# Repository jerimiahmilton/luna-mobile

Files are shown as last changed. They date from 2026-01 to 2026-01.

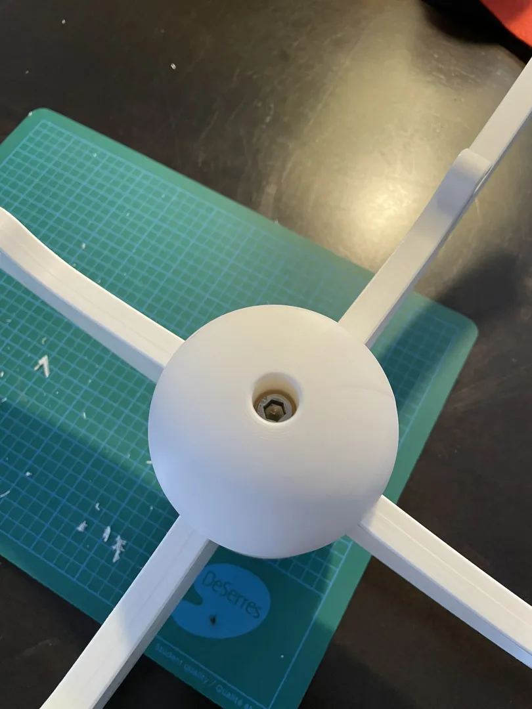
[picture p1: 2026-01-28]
reference/3mf_contents/Auxiliaries/Model Pictures/IMG_5841.webp

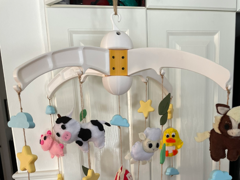
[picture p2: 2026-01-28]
reference/3mf_contents/Auxiliaries/.thumbnails/thumbnail_3mf.png

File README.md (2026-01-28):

# 🌙 Luna's Baby Mobile

A beautiful, motorized baby mobile designed for 3D printing. This project creates a gently rotating mobile that can be mounted to a ceiling or crib rail.

## ✨ Features

- **Motorized rotation** - Gentle ~3.75 RPM rotation using an N20 worm gear motor
- **Simple design** - Single-stage gear reduction (8:1) for reliability
- **Two mounting options** - Ceiling mount or adjustable crib rail clamp
- **Modular design** - 4 interchangeable arms with various hook styles
- **Dual power options** - 4xAA battery pack OR DC barrel jack for wall power
- **Baby-safe** - Rounded edges, no pinch points, secure mounting
- **Fully parametric** - Easy to customize dimensions in OpenSCAD
- **Easy assembly** - Press-fit and snap-fit connections

## 📦 What's Included

### OpenSCAD Files
| File | Description |
|---|---|
| `config.scad` | All parameters and dimensions |
| `gears.scad` | Involute gear generation library |
| `motor_mount.scad` | N20 motor housing (single shaft version) |
| `gear_assembly.scad` | Single-stage gear reduction (8:1) |
| `central_hub.scad` | Main hub with bearing seat |
| `arm_curved.scad` | **Curved arms with integrated hooks** (default) |
| `arm_straight.scad` | Original straight arms with end hooks |
| `ceiling_mount.scad` | Ceiling mounting bracket |
| `crib_clamp.scad` | Adjustable crib rail clamp |
| `battery_mount.scad` | 4xAA battery case holder |
| `switch_mount.scad` | Power switch bracket |
| `barrel_jack.scad` | DC barrel jack mount |
| `pdb_mount.scad` | Power Distribution Board (IA005) mount |
| `assembly.scad` | Complete assembly visualization |

### Pre-rendered STL Files
Located in `openscad/stl/` for immediate printing.

## 🔧 Specifications

### Motor (N20 Worm Gear - B-LA008, Single Shaft)
| Parameter | Value |
|---|---|
| Voltage | 6V DC (range: 3-7V) |
| Speed | ~30 RPM @ 6V |
| Shaft | Single, 4mm with D-flat |
| Current | ≤30mA |
| Direction | Clockwise |

### Bearing (608)
| Parameter | Value |
|---|---|
| Inner diameter | 8mm |
| Outer diameter | 22mm |
| Width | 7mm |

### Gear Reduction (Simplified!)
| Stage | Pinion | Gear | Ratio | Input RPM | Output RPM |
|---|---|---|---|---|---|
| Single | 12T | 96T | 8:1 | ~30 | **~3.75** |

*Much simpler than the previous two-stage 50:1 design!*

### Power Options

**Option 1: Battery Power (4xAA)**
| Parameter | Value |
|---|---|
| Voltage | 6V (4 × 1.5V) |
| Battery Case | IA003 (70×65×19mm) |
| Connector | PH2.0 |
| Runtime | ~40-60 hours |

**Option 2: Wall Power (DC Adapter)**
| Parameter | Value |
|---|---|
| Voltage | 6V DC |
| Jack | 5.5×2.1mm barrel |
| Current | 500mA+ recommended |

## 🛒 Bill of Materials

See [BOM.md](BOM.md) for the complete parts list with links and prices.

### Quick Parts List
- 1× N20 Worm Gear Motor (6V, ~30RPM, B-LA008)
- 2× 608 Bearings
- 1× 4xAA Battery Case (IA003, PH2.0)
- 1× Power Switch (XA007, XH2.54)
- 1× DC Barrel Jack (optional, XC008)
- Fasteners (M3, M4 screws)
- Wire, connectors

## 🖨️ Printing Guidelines

### Recommended Settings
| Setting | Value |
|---|---|
| Layer height | 0.2mm |
| Infill | 20-30% |
| Material | PLA or PETG |
| Supports | Only where noted |

### Print Times (approximate)
| Part | Time | Supports |
|---|---|---|
| Central Hub | 2-3 hours | No |
| Arms (×4) | 1 hour each | No |
| Ceiling Mount | 2 hours | Yes |
| Crib Clamp | 3-4 hours | Yes |
| Motor Mount | 1 hour | Minimal |
| Gear Housing | 1.5 hours | No |
| Motor Pinion | 15 min | No |
| Output Gear | 1 hour | No |
| Battery Mount | 1.5 hours | No |
| Switch Mount | 30 min | No |
| Barrel Jack Mount | 30 min | No |

### Tolerances
Adjust in `config.scad` if needed:
- Press fit: 0.15mm
- Loose fit: 0.3mm
- General: 0.2mm

## 🔨 Assembly Instructions

### 1. Print All Parts
Use the settings above. Check each part for quality before assembly.

### 2. Install Bearings
Press 608 bearings into:
- Ceiling mount (or crib clamp) bearing seat
- Gear housing output shaft position

### 3. Assemble Gear Train (Simplified!)
1. Press motor pinion (12T) onto motor D-shaft
2. Mount output gear (96T) on output shaft with bearing
3. Install gear housing with motor pinion engaged
4. Close gearbox with lid

### 4. Attach Motor to Mount
1. Slide motor into motor mount housing
2. Clips will snap over motor body
3. Route wires through exit slot

### 5. Assemble Hub & Arms
1. Insert arms into hub sockets (they snap-fit)
2. Attach hub adapter through bearing to output gear
3. Verify smooth rotation

### 6. Mount Assembly

**Ceiling Mount:**
1. Mark ceiling holes using mount as template
2. Install wall anchors if needed
3. Secure mount with M4 screws
4. Attach motor/gearbox assembly
5. Hang hub assembly

**Crib Clamp:**
1. Position clamp on crib rail
2. Tighten adjustment knob
3. Verify secure grip (no movement)
4. Attach mobile assembly

### 7. Electronics Assembly

**Wiring with Power Distribution Board (IA005):**

The IA005 provides clean power management with overcurrent protection and multiple outputs.

```
┌─────────────────────────────────────────────────────────────────────────┐
│                    POWER DISTRIBUTION WIRING                            │
├─────────────────────────────────────────────────────────────────────────┤
│                                                                         │
│  ┌─────────────┐      ┌─────────────────────────────────┐              │
│  │ 4xAA Battery│─────→│ IN (PH2.0)                      │              │
│  │   (IA003)   │      │                                 │              │
│  │   (PH2.0)   │      │         IA005 PDB               │              │
│  └─────────────┘      │   Power Distribution Board      │              │
│                       │                                 │              │
│  ┌─────────────┐      │ SW0 (SH1.0) ←── Master Switch   │              │
│  │ XA007 Switch│─────→│ (controls all outputs)          │              │
│  │  (XH2.54*)  │      │                                 │              │
│  └─────────────┘      │ CH1 (SH1.0) ───→ Motor ─────────┼──→ 🔄        │
│                       │ CH2 (SH1.0) ───→ (spare)        │              │
│  * May need adapter   │ CH3 (SH1.0) ───→ (spare)        │              │
│    or rewire to SH1.0 │ CH4 (SH1.0) ───→ (spare)        │              │
│                       │                                 │              │
│                       │ 💡 LED: White = OK              │              │
│                       │        Off = Overcurrent        │              │
│                       └─────────────────────────────────┘              │
│                                                                         │
└─────────────────────────────────────────────────────────────────────────┘
```

**Connection Summary:**
| From | To | Cable Type |
|---|----|---|
| Battery Case (IA003) | IA005 IN | PH2.0-2P (included) |
| IA005 CH1 | Motor | SH1.0-2P (included) |
| XA007 Switch | IA005 SW0 | SH1.0-2P* |

*Note: XA007 switch uses XH2.54 connector. You may need to re-terminate with SH1.0 or use an adapter.

**LED Indicator Behavior:**
- ⚪ **White LED ON** = Normal operation, power flowing
- ⚫ **LED OFF** = Overcurrent protection triggered (>1A), check connections

**Benefits of IA005:**
- ✅ Clean power distribution with labeled ports
- ✅ Overcurrent protection (max 1A per channel)
- ✅ Master switch input (SW0) controls all outputs
- ✅ 4 spare outputs for future accessories (LEDs, sensors, etc.)
- ✅ Easy daisy-chaining via OUT port

**Alternative: Direct Wiring (without PDB)**
```
┌─────────────┐    ┌──────────┐    ┌─────────┐
│ 4xAA Battery│───→│  Switch  │───→│  Motor  │
│   (PH2.0)   │    │ (XH2.54) │    │         │
└─────────────┘    └──────────┘    └─────────┘
```

**Alternative: Wall Power**
```
┌────────────┐    ┌──────────┐    ┌─────────┐
│ DC Adapter │───→│  Switch  │───→│  Motor  │
│ (6V, 5521) │    │ (XH2.54) │    │         │
└────────────┘    └──────────┘    └─────────┘
```

### 8. Add Mobile Elements
Hang decorative elements from arm hooks using string or fishing line.

## ⚠️ Safety Notes

- **Always supervise** - Never leave baby unattended with mobile
- **Height** - Mount at least 16" above mattress (out of reach)
- **Secure mounting** - Test stability before use
- **Regular inspection** - Check for loose parts weekly
- **Age limit** - Remove mobile when baby can push up on hands/knees (~5 months)
- **Cord safety** - Keep power cords away from crib, use cord covers

## 🎨 Customization

### Changing Dimensions
Edit `config.scad` to adjust:
- `arm_length` - Length of arms (default 180mm)
- `hub_arm_count` - Number of arms (default 4)
- `gear_module` - Gear size (affects overall gearbox size)
- `motor_rpm` - If using a different speed motor

### Arm Styles

Luna Mobile includes two arm designs:

**🌊 Curved Arms (Default)** — `arm_curved.scad`
- Elegant sweeping arc shape inspired by Scandinavian design
- **Two integrated downward-facing hooks** per arm for hanging decorations
- Decorative recessed channel along the top surface
- Mounting holes for secure hub attachment
- Perfect for the main decorative elements

**➖ Straight Arms** — `arm_straight.scad`
- Simple, clean design with hook at the end
- Multiple hook styles available:
  - Default curved hook
  - Loop hook
  - Star hook
  - Moon hook (🌙 for Luna!)
- Good for minimalist aesthetic or more elements

To switch arm styles, edit `config.scad`:
```openscad
use_curved_arms = true;   // Curved arms with integrated hooks (default)
use_curved_arms = false;  // Original straight arms
```

### Colors
Adjust the color variables in `config.scad` for different preview colors.

## 🔌 Connector Reference

| Component | Connector | Pin Count |
|---|---|---|
| Battery Case | JST PH2.0 | 2-pin |
| Power Switch | XH2.54 | 2-pin |
| DC Barrel Jack | 5.5×2.1mm | 2-wire |
| PDB Power IN/OUT | JST PH2.0 | 2-pin |
| PDB Switch Inputs | JST SH1.0 | 2-pin |
| PDB Device Outputs | JST SH1.0 | 2-pin |

**Adapter cables** may be needed to connect these. Search for "PH2.0 to XH2.54" adapters, or make your own with crimp terminals.

**Note:** The IA005 PDB includes SH1.0 jumper cables, making it easy to connect to motors and switches directly.

## 📝 License

MIT License - See [LICENSE](LICENSE)

Feel free to modify, share, and sell prints!

## 💕 Credits

Designed with love for Luna.

Made for Jeremy's newborn daughter — may she have sweet dreams and endless wonder! 🌙✨

---

*Made with OpenSCAD and lots of coffee ☕*

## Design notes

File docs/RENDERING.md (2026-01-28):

# Rendering STL Files

The OpenSCAD files need to be rendered to STL for 3D printing.

## Using OpenSCAD GUI

1. Open any `.scad` file in OpenSCAD
2. Press F6 to render
3. Export → Export as STL

## Command Line Rendering

```bash
# Render individual parts
openscad -o stl/central_hub.stl openscad/central_hub.scad
openscad -o stl/arm.stl openscad/arm.scad
openscad -o stl/ceiling_mount.stl openscad/ceiling_mount.scad
openscad -o stl/motor_mount.stl openscad/motor_mount.scad
openscad -o stl/crib_clamp.stl openscad/crib_clamp.scad

# Render gears (export each part separately by uncommenting in gear_assembly.scad)
openscad -o stl/stage1_pinion.stl -D 'part="pinion1"' openscad/gear_assembly.scad
```

## Recommended Render Settings

For final STL export, increase resolution in `config.scad`:

```openscad
$fn = 128;  // Higher = smoother curves, longer render time
```

## Preview vs Render

- **F5 (Preview)** - Fast, for checking design
- **F6 (Render)** - Full quality, required before STL export

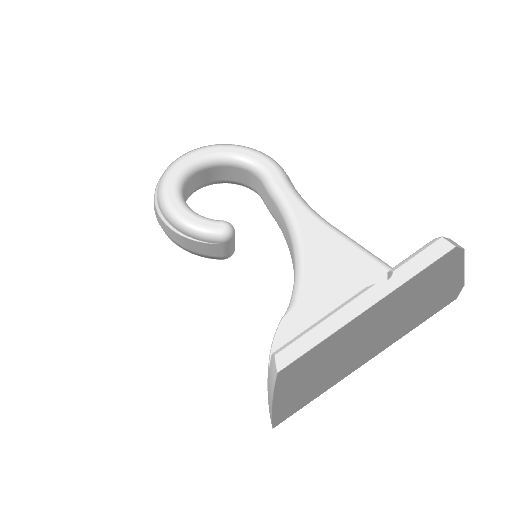
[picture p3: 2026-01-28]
reference/3mf_contents/Metadata/plate_4.png

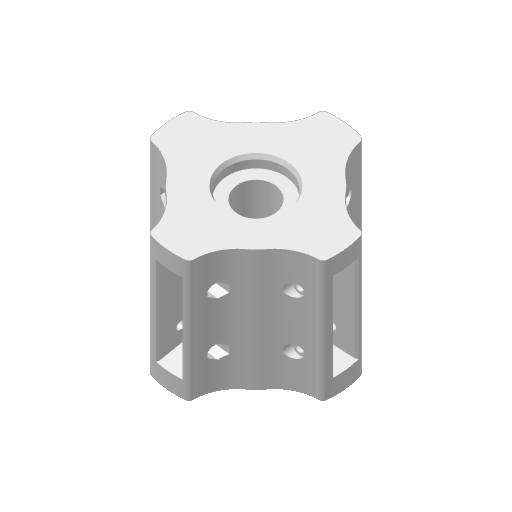
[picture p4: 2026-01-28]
reference/3mf_contents/Metadata/plate_2.png

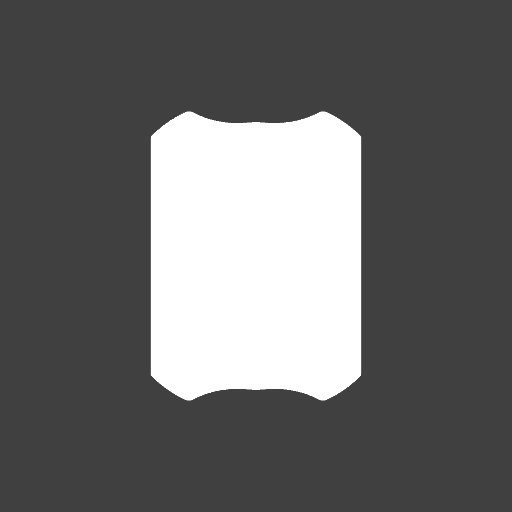
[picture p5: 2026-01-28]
reference/3mf_contents/Metadata/plate_no_light_2.png

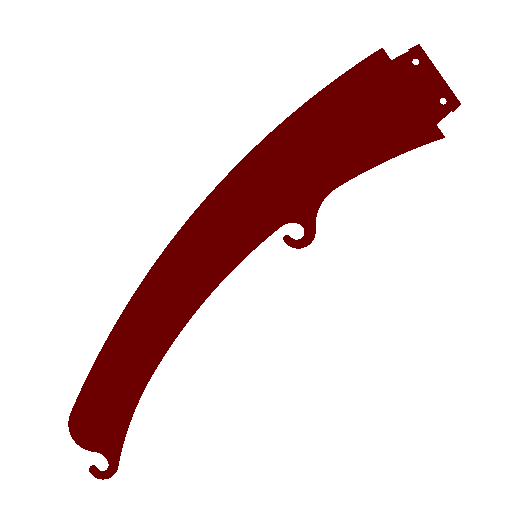
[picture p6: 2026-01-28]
reference/3mf_contents/Metadata/pick_1.png

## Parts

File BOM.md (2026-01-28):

# 📋 Bill of Materials - Luna's Baby Mobile

## 🖨️ 3D Printed Parts

### Mechanical Components
| Qty | Part | File | Print Time | Supports |
|-----|---|---|---|---|
| 1 | Central Hub | `central_hub.scad` | ~2.5 hrs | No |
| 4 | Arms | `arm.scad` | ~1 hr each | No |
| 1 | Ceiling Mount | `ceiling_mount.scad` | ~2 hrs | Yes |
| 1 | Crib Clamp Body | `crib_clamp.scad` | ~3 hrs | Yes* |
| 1 | Crib Clamp Jaw | `crib_clamp.scad` | ~1 hr | Yes* |
| 1 | Clamp Knob | `crib_clamp.scad` | ~30 min | No* |
| 1 | Motor Mount | `motor_mount.scad` | ~1 hr | Minimal |
| 1 | Gearbox Housing | `gear_assembly.scad` | ~1.5 hrs | No |
| 1 | Gearbox Lid | `gear_assembly.scad` | ~20 min | No |
| 1 | Motor Pinion (12T) | `gear_assembly.scad` | ~15 min | No |
| 1 | Output Gear (96T) | `gear_assembly.scad` | ~1 hr | No |
| 1 | Output Shaft | `gear_assembly.scad` | ~15 min | No |

*Only needed if using crib mount*

### Electronics Mounts
| Qty | Part | File | Print Time | Supports |
|-----|---|---|---|---|
| 1 | Battery Cradle Mount | `battery_mount.scad` | ~1.5 hrs | No |
| 1 | Switch Panel Mount | `switch_mount.scad` | ~30 min | No |
| 1 | Barrel Jack Mount | `barrel_jack.scad` | ~30 min | No* |
| 1 | PDB Mount (IA005) | `pdb_mount.scad` | ~45 min | No |

*Optional - only needed for wall power*

**Total print time:** ~15-18 hours (depending on mount choice and settings)

**Filament estimate:** ~250-300g PLA/PETG

---

## ⚡ Electronics

### Motor
| Qty | Item | Model | Specifications | Est. Price |
|-----|---|---|---|---|
| 1 | N20 Worm Gear Motor | B-LA008 | 6V, ~30RPM, single shaft, CW | $4-8 |

**Search terms:** "N20 worm gear motor 6V 25RPM single shaft" or "B-LA008"

**Key specs to verify:**
- Voltage: 6V (range 3-7V OK)
- Speed: 25-34 RPM
- Single shaft output (not dual)
- 4mm D-shaft

### Power Supply Components
| Qty | Item | Model | Specifications | Est. Price |
|-----|---|---|---|---|
| 1 | 4xAA Battery Case | IA003 | 70×65×19mm, PH2.0 connector | $2-4 |
| 1 | Power Switch Module | XA007 | On/Off, XH2.54 connector, 3A max | $2-3 |
| 1 | Power Distribution Board | IA005 | 53×10×10mm, 1A max, M2 mount | $5.29 |
| 1 | DC Barrel Jack* | XC008 | 5.5×2.1mm, panel mount, 12mm hole | $1-2 |
| 1 | 6V DC Adapter* | - | 5.5×2.1mm plug, 500mA+ | $5-10 |

*Optional - for wall power*

**IA005 Power Distribution Board Includes:**
- USB power cable
- PH2.0-2P wire pair (for battery connection)
- 5× SH1.0 jumper cables (for switches and device outputs)

**IA005 Specifications:**
- Size: 53 × 10 × 10mm, Weight: 3g
- Max current: 1A per channel, Max voltage: 7.4V
- Connectors: IN/OUT (PH2.0-2P), SW0-4 (SH1.0-2P), CH1-4 (SH1.0-2P)
- SW0 acts as master switch controlling all outputs
- White LED indicator (off = overcurrent protection triggered)

### Wiring & Connectors
| Qty | Item | Specifications | Est. Price |
|-----|---|---|---|
| 1 | PH2.0 to XH2.54 Adapter | 2-pin, 100-150mm | $1-2 |
| 2ft | 22-24 AWG Wire | Stranded, red & black | $2-3 |
| - | Heat Shrink Tubing | Assorted sizes | $3-5 |
| 2 | JST XH2.54 Connectors | 2-pin, male | $1-2 |

**Note:** The battery case (PH2.0) and switch (XH2.54) use different connectors. You'll need an adapter cable or make your own connections.

---

## 🔩 Bearings

| Qty | Item | Specifications | Est. Price |
|-----|---|---|---|
| 2 | 608 Bearing | 8×22×7mm, standard | $5-8 (pack of 10) |

*Standard skateboard bearings - very common and cheap!*

---

## 🔧 Hardware

### Fasteners
| Qty | Item | Use | Est. Price |
|-----|---|-----|---|
| 4 | M3 × 10mm Screw | Motor mount, electronics | $2-3 |
| 4 | M4 × 20mm Screw | Ceiling mount | $2-3 |
| 4 | M4 Wall Anchors | Ceiling (drywall) | $3-5 |
| 1 | M6 × 60mm Bolt | Crib clamp adjustment* | $1-2 |
| 1 | M6 Nut | Crib clamp* | $0.50 |
| 1 | M6 Wing Nut | Easier adjustment* | $1 |
| 4 | M2.5 × 8mm Screw | Gearbox lid | $1-2 |

*Only for crib mount option*

---

## 🎨 Decorative Elements (Optional)

### Mobile Hanging Elements
| Qty | Item | Suggestions | Est. Price |
|-----|---|---|---|
| 4-8 | Felt Shapes | Stars ⭐, moons 🌙, clouds ☁️, hearts ❤️ | $5-15 |
| 4-8 | Wooden Beads | 20-30mm, natural or painted | $5-10 |
| - | Pom Poms | Various sizes and colors | $3-5 |
| 1 | Fishing Line | 10-20lb test, clear | $3-5 |
| 1 | Embroidery Thread | For hanging elements | $2-3 |

### Finishing (Optional)
| Qty | Item | Use | Est. Price |
|-----|---|-----|---|
| 1 | Sandpaper | 220-400 grit | $3-5 |
| 1 | Primer | For painting | $5-8 |
| 1 | Acrylic Paint | Baby-safe, water-based | $3-5 |
| 1 | Clear Coat | Protective finish | $5-8 |

---

## 🛡️ Safety Items

| Qty | Item | Purpose | Est. Price |
|-----|---|---|---|
| 4 | Rubber Pads | Crib clamp grip | $3-5 |
| 1 | Cord Cover | Hide power cable | $5-10 |
| 1 | Cord Shortener | Keep cord safe | $3-5 |

---

## 💰 Cost Summary

| Category | Basic | With Decorations |
|---|---|---|
| Filament (~300g) | $6-10 | $6-10 |
| Motor | $4-8 | $4-8 |
| Bearings | $5-8 | $5-8 |
| Battery Case | $2-4 | $2-4 |
| Switch | $2-3 | $2-3 |
| Power Distribution Board (IA005) | $5-6 | $5-6 |
| Barrel Jack + Adapter | $6-12 | $6-12 |
| Connectors/Wire | $5-10 | $5-10 |
| Fasteners | $8-12 | $8-12 |
| Decorative | - | $15-35 |
| Safety Items | $10-20 | $10-20 |
| **Total** | **$55-90** | **$70-125** |

---

## 🔗 Suggested Suppliers

### Electronics & Motors
| Supplier | Notes |
|---|---|
| AliExpress | Best prices, 2-4 week shipping |
| Amazon | Fast shipping, higher prices |
| Banggood | Good selection, moderate shipping |
| Adafruit/SparkFun | Quality, US-based, premium prices |

### Hardware
| Supplier | Notes |
|---|---|
| Home Depot / Lowes | Local, immediate |
| McMaster-Carr | Professional quality |
| Amazon | Convenience, variety packs |
| Bolt Depot | Specialty fasteners |

### 3D Printing Supplies
| Supplier | Notes |
|---|---|
| Prusa | Quality filament |
| Overture | Good value on Amazon |
| Hatchbox | Popular, reliable |
| eSUN | Budget-friendly |

### Craft Supplies
| Supplier | Notes |
|---|---|
| Michaels / Joann | Local craft stores |
| Etsy | Handmade mobile elements |
| Amazon | Bulk supplies |

---

## 📝 Notes

### Motor Selection
The B-LA008 is the recommended motor. Key differences from the old design:
- **Old (B-LA009):** Dual shaft, 150 RPM @ 3V
- **New (B-LA008):** Single shaft, ~30 RPM @ 6V

The slower motor with single shaft simplifies the design significantly!

### Power Considerations
| Power Source | Voltage | Runtime | Notes |
|---|---|---|---|
| 4× AA Alkaline | 6V | 40-60 hrs | Portable, no wires |
| 4× AA Rechargeable | 4.8V | 30-50 hrs | Slightly slower rotation |
| 6V DC Adapter | 6V | Unlimited | Requires outlet nearby |

### Connector Compatibility
```
Battery Case (IA003) → PH2.0 connector
Switch (XA007)      → XH2.54 connector
```

These are different connector families! Solutions:
1. **Buy an adapter cable** - Search "JST PH2.0 to XH2.54"
2. **Make your own** - Cut and solder/crimp
3. **Bypass connectors** - Solder wires directly

### Battery Life Calculation
```
Motor current: ~30mA
AA battery capacity: ~2000mAh (alkaline)
Runtime: 2000 ÷ 30 = ~66 hours theoretical
Real-world: ~40-60 hours (accounting for losses)
```

---

## 🌙 For Luna

This mobile was designed with love for Jeremy's newborn daughter Luna. May the gentle rotation and soft decorations bring her peaceful dreams!

💕 Made with care, powered by coffee ☕

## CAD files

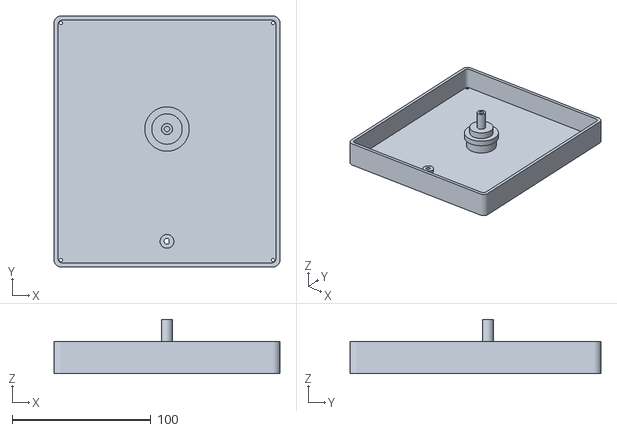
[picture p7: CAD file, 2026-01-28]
stl/gear_assembly.stl
163.0 x 181.0 x 39.0

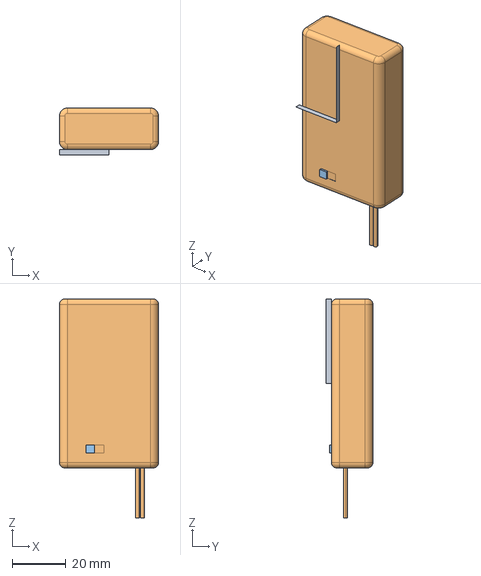
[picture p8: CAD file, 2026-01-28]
models/Battery Case/3x1.5V AAA Battery Case with XH2.54 Connector-XA012/3x1.5V AAA Battery Case with XH2.54 Connector-XA012.stp
37.0 x 17.5 x 81.7 mm

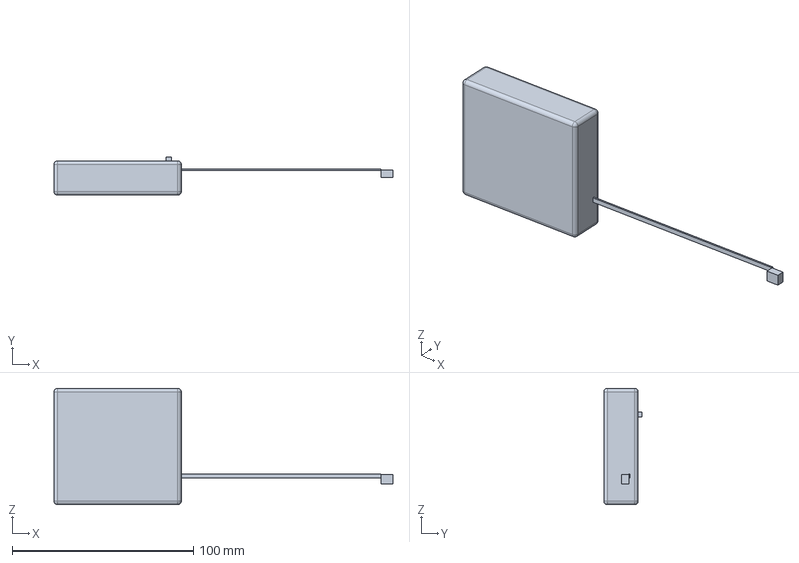
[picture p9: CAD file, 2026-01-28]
models/Battery Case/Battery Case with PH2.0 Connector - IA003/AA_battery_case_with_wire_ph2_0.stp
186.9 x 21.2 x 64.2 mm

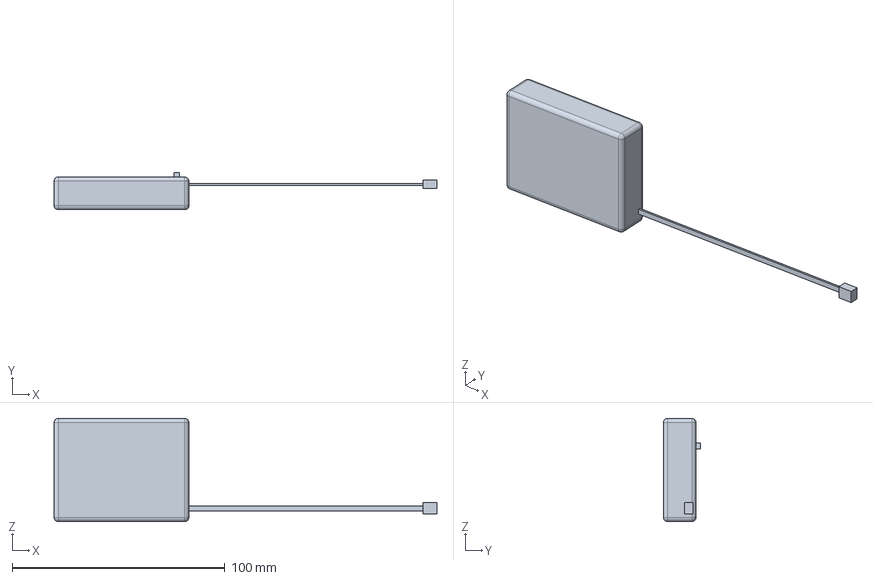
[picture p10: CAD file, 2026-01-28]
models/Battery Case/Battery Case with PH2.0 Connector - IA004/AAA_battery_case_with_wire_ph2_0.stp
180.2 x 17.6 x 48.5 mm

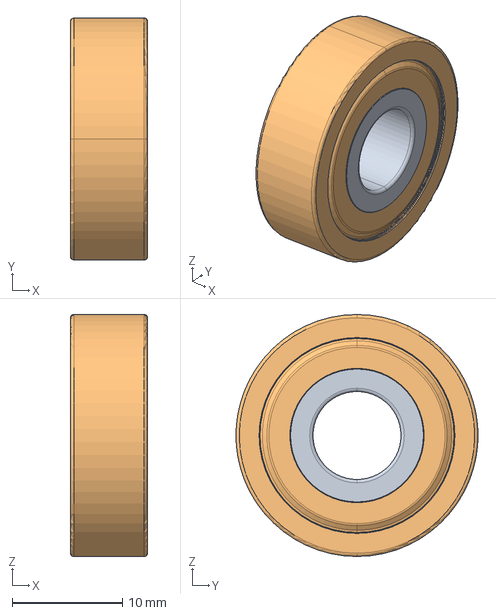
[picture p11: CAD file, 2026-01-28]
models/High Performance Bearings/608 Open - EA029/608 Open - EA029.stp
7.00 x 22.0 x 22.0 mm

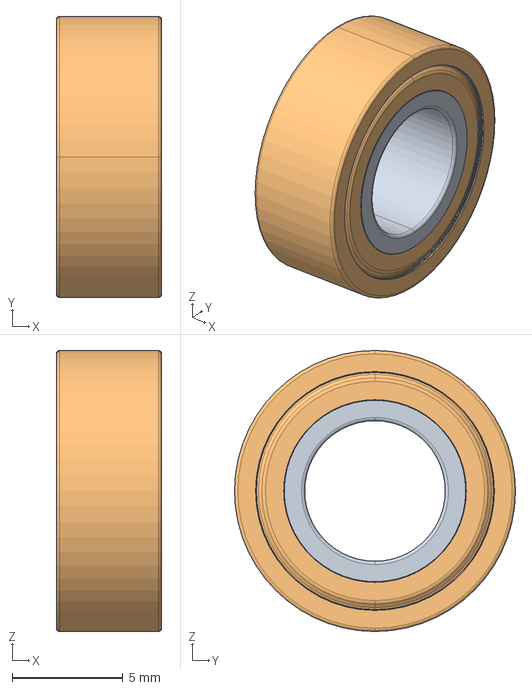
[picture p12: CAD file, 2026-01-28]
models/High Performance Bearings/R188 Open - EA022/R188 Open - EA022.stp
4.76 x 12.7 x 12.7 mm

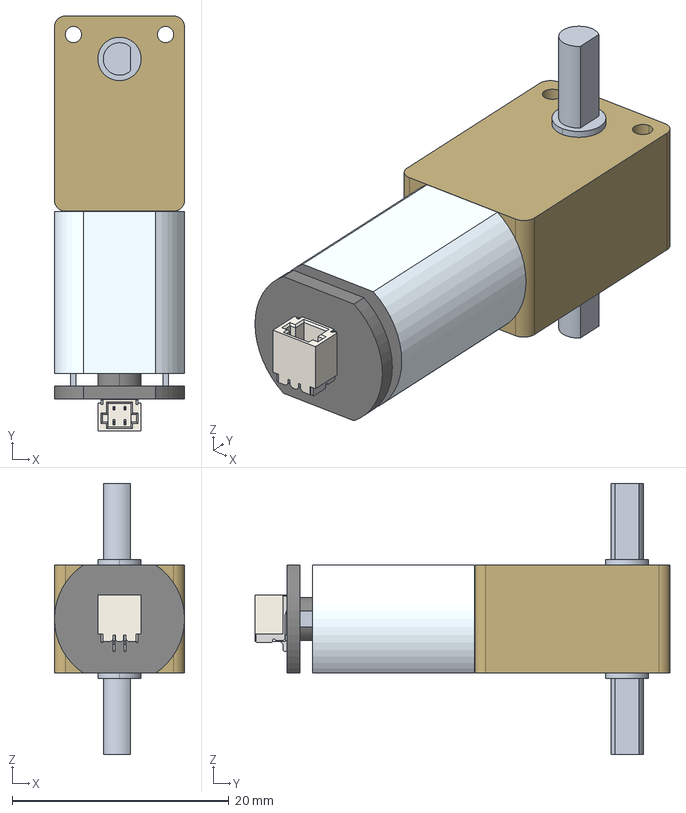
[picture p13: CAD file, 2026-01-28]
models/N20 Dual Shaft Worm Gear Motor/N20 Dual Shaft Worm - LA009.stp
12.0 x 38.3 x 25.0 mm

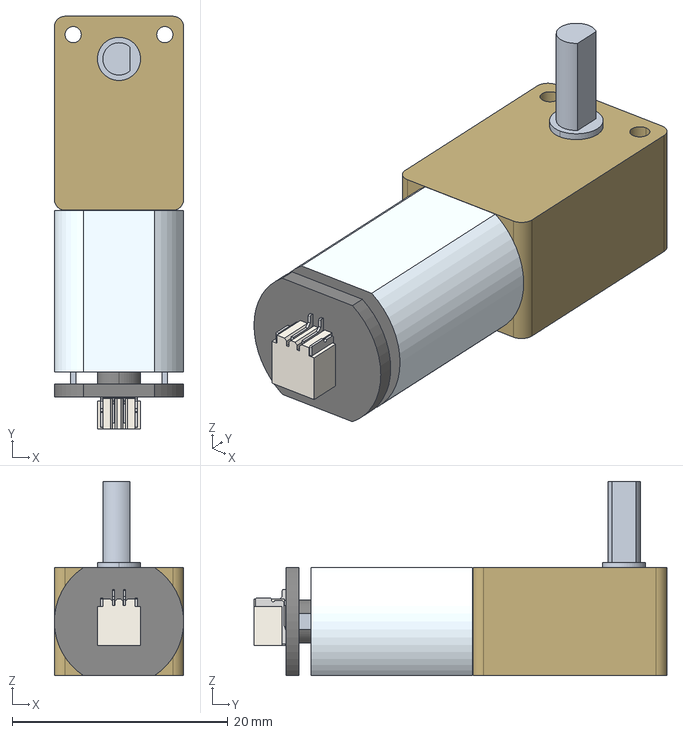
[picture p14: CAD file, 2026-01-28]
models/N20 Single Shaft Worm Gear Motor/N20 Single Shaft Worm - LA008.stp
12.0 x 38.3 x 18.0 mm

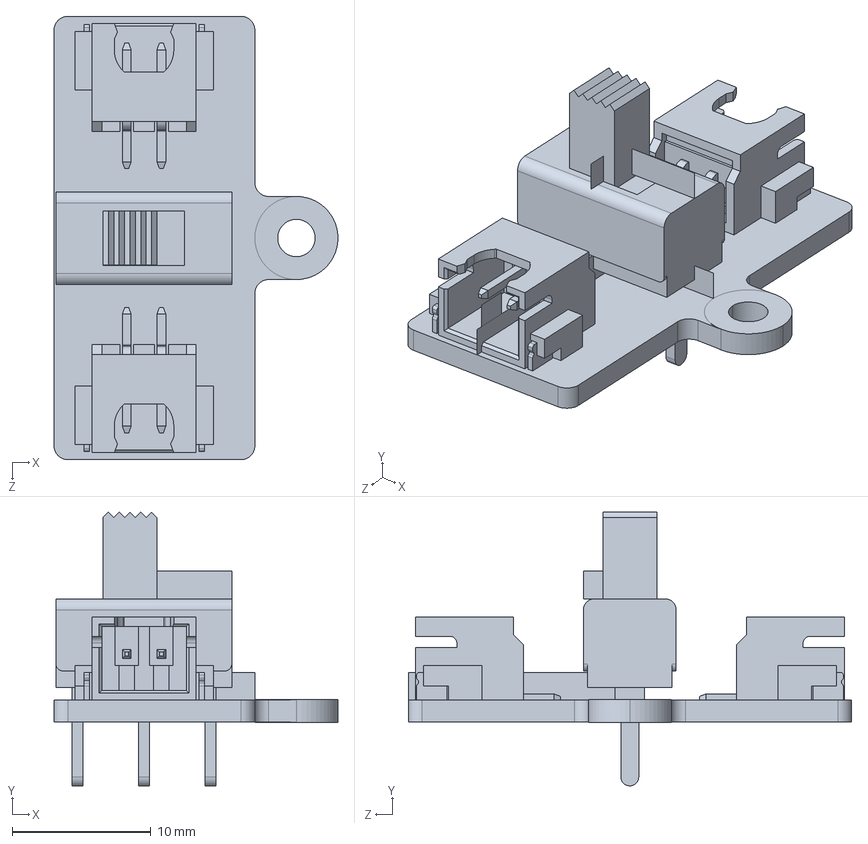
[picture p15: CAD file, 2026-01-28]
models/Power Switch Board with 2Pin XH2.54 Connector-XA007/Power Switch Board with 2Pin XH2.54 Connector-XA007.STEP
20.5 x 19.8 x 32.0 mm
SWITCH-2_54-PCB^Power Switch Board with 2Pin XH2.54 Connector-XA007(2)_Power Switch Board with 2Pin XH2.54 Connector-XA007
SWITCH-FOR-BATTERY^Power Switch Board with 2Pin XH2.54 Connector-XA007(2)_Power Switch Board with 2Pin XH2.54 Connector-XA007
DIANYUAN-B^Power Switch Board with 2Pin XH2.54 Connector-XA007(2)_Power Switch Board with 2Pin XH2.54 Connector-XA007 x 2

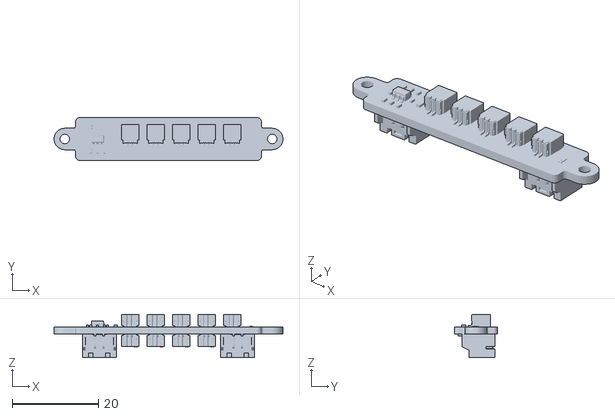
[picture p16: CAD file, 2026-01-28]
models/Power-Distribution-Board-IA005/Power Distribution Board (PDB)/power_distribution_board_new.stl
53.0 x 9.97 x 10.1

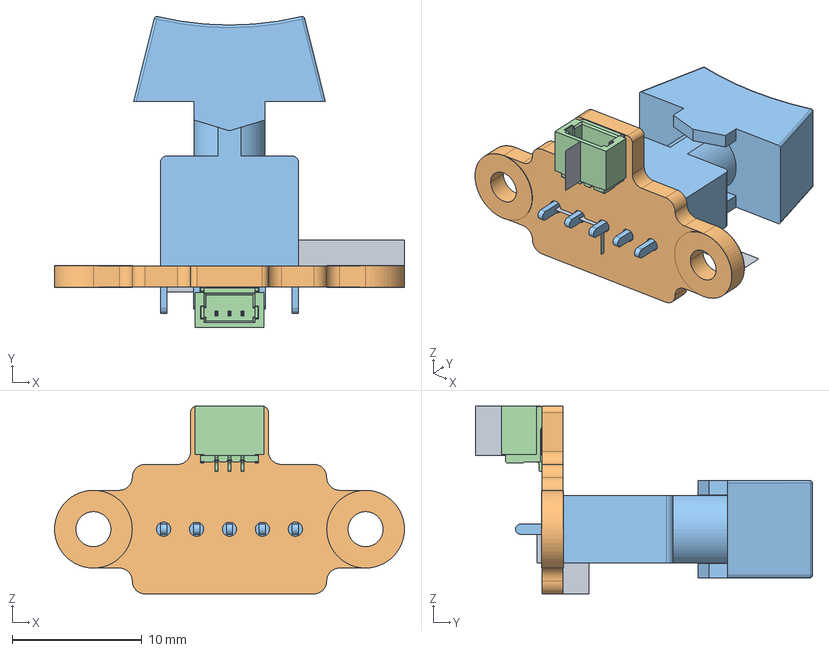
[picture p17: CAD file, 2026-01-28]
models/Three-Position Rocker Switch Module with 3Pin SH1.0 Connector-XA010.stp
27.0 x 26.0 x 14.5 mm
GSR-0-103-A02-0005-RS-PCB
GSR-0-103-A02-0005-RS
1_0-3PIN

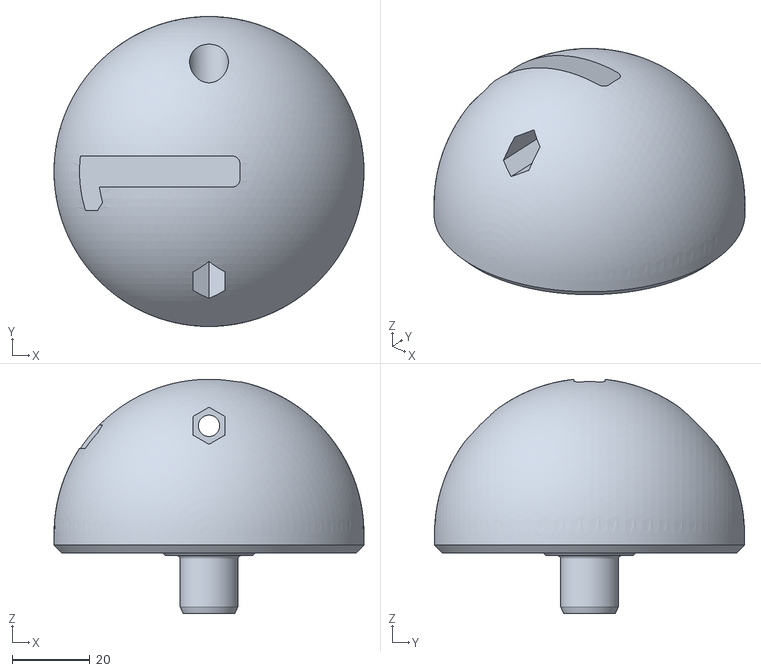
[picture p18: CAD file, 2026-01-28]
reference/obj_5_CenterPart - Top4 - NutEmbeded.step.stl
80.0 x 80.0 x 60.5

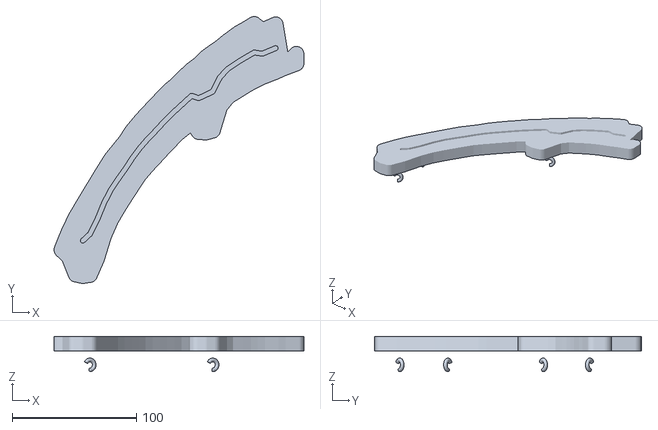
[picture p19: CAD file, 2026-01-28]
stl/arm_reference.stl
201.0 x 214.8 x 28.5

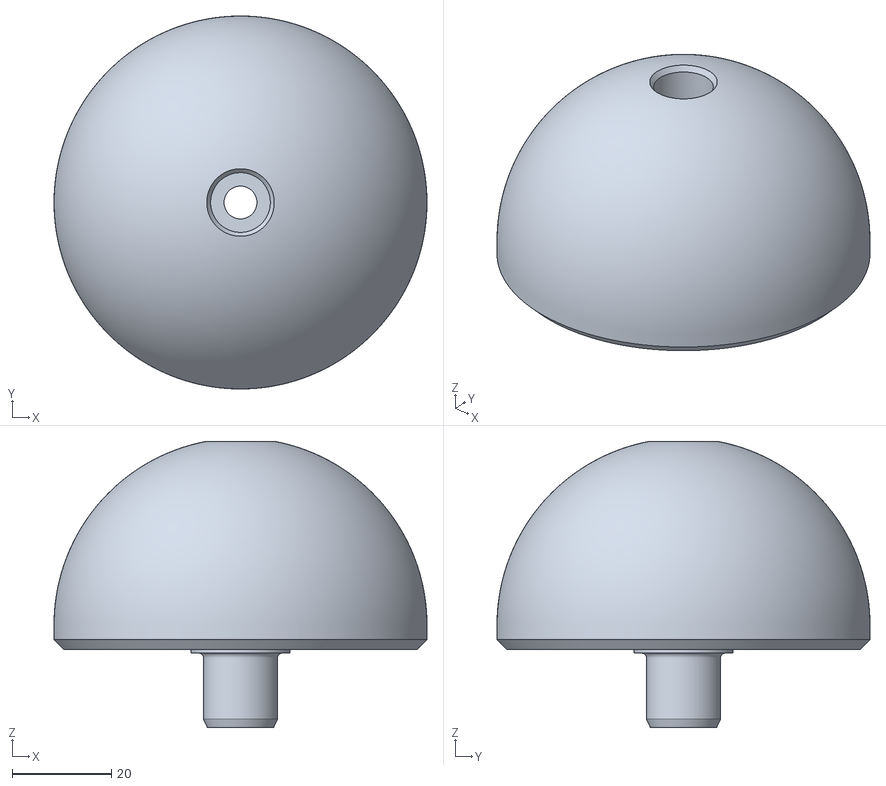
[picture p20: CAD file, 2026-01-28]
reference/obj_2_CenterPart - Bottom.STEP.stl
75.0 x 75.0 x 57.6

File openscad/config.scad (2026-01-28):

// ============================================================================
// Luna's Baby Mobile - Configuration File
// ============================================================================
// A gift for Jeremy's newborn daughter 💕
// All dimensions in millimeters
// ============================================================================

// ----------------------------------------------------------------------------
// PRINT SETTINGS & TOLERANCES
// ----------------------------------------------------------------------------
$fn = 64;                           // Resolution for curves (increase for final render)
tolerance = 0.2;                    // General fit tolerance
press_fit_tolerance = 0.15;         // Tighter tolerance for press fits
loose_fit_tolerance = 0.3;          // Looser tolerance for easy assembly
layer_height = 0.2;                 // Assumed layer height for design decisions

// ----------------------------------------------------------------------------
// 608 BEARING SPECIFICATIONS (Standard skateboard bearing)
// ----------------------------------------------------------------------------
bearing_inner_diameter = 8;         // Inner bore diameter
bearing_outer_diameter = 22;        // Outer race diameter
bearing_width = 7;                  // Bearing width/thickness
bearing_chamfer = 0.5;              // Small chamfer on bearing edges

// ----------------------------------------------------------------------------
// N20 WORM GEAR MOTOR SPECIFICATIONS (B-LA008 - Single Shaft)
// ----------------------------------------------------------------------------
// Updated to single shaft worm gear motor for simpler design
motor_body_length = 24;             // Main motor body length (excluding gearbox)
motor_body_diameter = 12;           // Motor body diameter
motor_gearbox_length = 9.2;         // Worm gearbox length
motor_gearbox_width = 12;           // Gearbox width
motor_gearbox_height = 10;          // Gearbox height
motor_total_length = 33.2;          // Total motor + gearbox length
motor_shaft_diameter = 4;           // Output shaft diameter
motor_shaft_flat_depth = 0.5;       // D-flat depth
motor_shaft_length = 10;            // Output shaft length (single side only)
motor_mounting_hole_spacing = 8;    // Distance between mounting holes
motor_mounting_hole_diameter = 2;   // M2 mounting screw holes
motor_rpm = 30;                     // RPM at 6V (~25-34 RPM, design for 30)
motor_voltage = 6.0;                // Rated voltage (range: 3-7V)
motor_current = 30;                 // Max current in mA
motor_rotation = "CW";              // Clockwise rotation

// ----------------------------------------------------------------------------
// GEAR SPECIFICATIONS (SIMPLIFIED)
// ----------------------------------------------------------------------------
// With 30 RPM motor, we only need ~8:1 reduction for 3-4 RPM output
gear_module = 1.5;                  // Gear module (tooth size) - 1.5mm for printability
gear_pressure_angle = 20;           // Standard pressure angle
gear_backlash = 0.1;                // Backlash for smooth operation
gear_height = 8;                    // Gear thickness

// Single stage reduction: 30 RPM -> ~3.75 RPM
// 8:1 reduction (12 tooth pinion, 96 tooth gear)
pinion_teeth = 12;                  // Motor pinion (minimum practical size)
gear_teeth = 96;                    // Output gear
gear_ratio = gear_teeth / pinion_teeth;  // 8:1

// Target output RPM
target_rpm = motor_rpm / gear_ratio;  // 30 / 8 = 3.75 RPM

// ----------------------------------------------------------------------------
// BATTERY CASE SPECIFICATIONS (IA003 - 4xAA with PH2.0)
// ----------------------------------------------------------------------------
battery_case_length = 70;           // Length (along batteries)
battery_case_width = 65;            // Width
battery_case_height = 19;           // Height/thickness
battery_case_voltage = 6.0;         // 4x 1.5V in series
battery_connector_type = "PH2.0";   // JST PH2.0 connector

// Mounting dimensions
battery_mount_wall = 2.5;           // Wall thickness for mount
battery_mount_tab_width = 10;       // Width of retention tabs
battery_mount_clearance = 0.5;      // Extra clearance for easy insertion

// ----------------------------------------------------------------------------
// POWER SWITCH SPECIFICATIONS (XA007)
// ----------------------------------------------------------------------------
switch_length = 29;                 // Length of switch module
switch_width = 13;                  // Width
switch_height = 15.2;               // Height (includes actuator)
switch_connector_type = "XH2.54";   // XH2.54 2-pin connector
switch_max_voltage = 12.6;          // Maximum voltage
switch_max_current = 3000;          // Maximum current in mA (3A)

// Mounting dimensions
switch_mount_wall = 2;              // Wall thickness
switch_actuator_height = 8;         // Height of switch actuator above base
switch_mount_clearance = 0.3;       // Clearance for fit

// ----------------------------------------------------------------------------
// DC BARREL JACK SPECIFICATIONS (XC008 - 5.5x2.1mm)
// ----------------------------------------------------------------------------
barrel_jack_plug_outer = 5.5;       // Plug outer diameter
barrel_jack_plug_inner = 2.1;       // Plug inner diameter (center pin)
barrel_jack_panel_hole = 12;        // Panel mount hole diameter
barrel_jack_body_length = 14;       // Body length behind panel
barrel_jack_flange_diameter = 14;   // Mounting flange diameter
barrel_jack_wire_length = 165;      // Wire length from jack
barrel_jack_nut_depth = 3;          // Depth of mounting nut

// ----------------------------------------------------------------------------
// CENTRAL HUB SPECIFICATIONS
// ----------------------------------------------------------------------------
hub_outer_diameter = 60;            // Outer diameter of hub
hub_height = 20;                    // Total hub height
hub_wall_thickness = 3;             // Wall thickness
hub_arm_count = 4;                  // Number of arms (evenly spaced)
hub_arm_socket_diameter = 10;       // Diameter of arm attachment socket
hub_arm_socket_depth = 12;          // Depth of arm socket

// ----------------------------------------------------------------------------
// ARM SPECIFICATIONS (Straight Arms - arm_straight.scad)
// ----------------------------------------------------------------------------
arm_length = 180;                   // Arm length (parametric: 150-200mm recommended)
arm_width = 12;                     // Arm cross-section width
arm_thickness = 6;                  // Arm cross-section thickness
arm_plug_diameter = 10 - tolerance; // Plug diameter (matches socket)
arm_plug_length = 10;               // Length of plug that goes into hub
arm_hook_diameter = 8;              // Hook inner diameter for hanging elements
arm_hook_thickness = 4;             // Hook wire thickness

// ----------------------------------------------------------------------------
// CURVED ARM SPECIFICATIONS (arm_curved.scad) - DEFAULT
// ----------------------------------------------------------------------------
// Elegant curved arms with integrated hooks for hanging decorations
// Scandinavian-inspired minimalist design

// Main dimensions (inspired by reference: ~56mm x 86mm)
arm_curved_length = 85;             // Length of curved arm
arm_curved_width = 14;              // Width of arm cross-section
arm_curved_height = 8;              // Height/thickness of arm

// Curve shape
arm_curve_arc_height = 12;          // Height of arc peak (creates gentle sweep)
arm_curve_segments = 64;            // Smoothness of curve (higher = smoother)

// Integrated hooks (2 per arm by default)
arm_hook_count = 2;                 // Number of downward-facing hooks
arm_hook_inner_dia = 6;             // Hook opening diameter (for string/ribbon)
arm_hook_wire = 3;                  // Thickness of hook "wire"
arm_hook_depth = 12;                // How far hooks extend downward
arm_hook_opening = 45;              // Opening angle (for easy string attachment)

// Mounting tab (for attachment to hub)
arm_mount_hole_dia = 3.2;           // M3 clearance hole
arm_mount_spacing = 10;             // Distance between mounting holes
arm_mount_length = 18;              // Length of mounting tab
arm_mount_width = 20;               // Width of mounting tab

// Aesthetic channels (decorative grooves)
arm_channel_width = 4;              // Width of recessed channels
arm_channel_depth = 1.5;            // Depth of channels
arm_channel_count = 2;              // Number of parallel channels

// Arm style selection (for assembly.scad)
use_curved_arms = true;             // true = curved arms, false = straight arms
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

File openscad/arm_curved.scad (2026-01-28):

// ============================================================================
// Luna's Baby Mobile - Curved Arms with Integrated Hooks
// ============================================================================
// Elegant curved arms inspired by Scandinavian design
// Features a sweeping arc shape with integrated downward hooks
// for hanging decorations
// 
// PRINT ORIENTATION: Model is oriented on its side for printing
// (curve profile pointing up, like a rainbow on its side)
// ============================================================================

include <config.scad>

// ----------------------------------------------------------------------------
// CURVED ARM PARAMETERS (can be overridden)
// ----------------------------------------------------------------------------
// These provide defaults if not defined in config.scad

// Arm dimensions
curved_arm_length = is_undef(arm_curved_length) ? 85 : arm_curved_length;
curved_arm_width = is_undef(arm_curved_width) ? 14 : arm_curved_width;
curved_arm_height = is_undef(arm_curved_height) ? 8 : arm_curved_height;

// Curve parameters
curve_arc_height = is_undef(arm_curve_arc_height) ? 12 : arm_curve_arc_height;
curve_segments = is_undef(arm_curve_segments) ? 64 : arm_curve_segments;

// Hook parameters
hook_count = is_undef(arm_hook_count) ? 2 : arm_hook_count;
hook_inner_diameter = is_undef(arm_hook_inner_dia) ? 6 : arm_hook_inner_dia;
hook_wire_thickness = is_undef(arm_hook_wire) ? 3 : arm_hook_wire;
hook_depth = is_undef(arm_hook_depth) ? 12 : arm_hook_depth;
hook_opening_angle = is_undef(arm_hook_opening) ? 45 : arm_hook_opening;

// Mounting parameters  
mount_tab_length = is_undef(arm_mount_length) ? 18 : arm_mount_length;
mount_tab_width = is_undef(arm_mount_width) ? 20 : arm_mount_width;

// Aesthetic channel parameters
channel_width = is_undef(arm_channel_width) ? 4 : arm_channel_width;
channel_depth = is_undef(arm_channel_depth) ? 1.5 : arm_channel_depth;
channel_count = is_undef(arm_channel_count) ? 2 : arm_channel_count;

// ----------------------------------------------------------------------------
// HELPER FUNCTIONS
// ----------------------------------------------------------------------------

// Compute point on the curved arm centerline
// Uses a parabolic arc for elegant sweep
function arm_curve_point(t) = [
    t * curved_arm_length,
    0,
    curve_arc_height * 4 * t * (1 - t)  // Parabolic arc, peaks at t=0.5
];

// Width taper along arm (wider at mount, narrower at tip)
function arm_width_at(t) = curved_arm_width * (1 - 0.2 * t);

// Height taper along arm
function arm_height_at(t) = curved_arm_height * (1 - 0.15 * t);

// ----------------------------------------------------------------------------
// CURVED ARM BODY
// ----------------------------------------------------------------------------

module curved_arm_body() {
    // Build the curved arm using hull between cross-sections
    steps = curve_segments;
    
    for (i = [0:steps-1]) {
        t1 = i / steps;
        t2 = (i + 1) / steps;
        
        p1 = arm_curve_point(t1);
        p2 = arm_curve_point(t2);
        
        w1 = arm_width_at(t1);
        w2 = arm_width_at(t2);
        h1 = arm_height_at(t1);
        h2 = arm_height_at(t2);
        
        hull() {
            translate(p1)
            arm_cross_section(w1, h1);
            
            translate(p2)
            arm_cross_section(w2, h2);
        }
    }
}

// Rounded rectangular cross-section (stadium/pill shape)
module arm_cross_section(w, h) {
    // Horizontal pill shape - rounded ends
    hull() {
        translate([0, -w/2 + h/2, 0])
        sphere(d = h, $fn = 16);
        translate([0, w/2 - h/2, 0])
        sphere(d = h, $fn = 16);
    }
}

// ----------------------------------------------------------------------------
// MOUNTING TAB (solid, no holes - connection method TBD)
// ----------------------------------------------------------------------------

module mounting_tab() {
    // Solid tab body - extends from arm base
    hull() {
        // Connection to arm
        translate([0, 0, 0])
        arm_cross_section(curved_arm_width, curved_arm_height);
        
        // Tab end (flat for mounting)
        translate([-mount_tab_length + 5, 0, -curved_arm_height/2])
        linear_extrude(height = curved_arm_height)
        offset(r = 3)
        square([mount_tab_length - 10, mount_tab_width - 6], center = true);
    }
}

// ----------------------------------------------------------------------------
// INTEGRATED HOOKS
// ----------------------------------------------------------------------------

module hook_integrated(flip = false) {
    // Simple C-shaped hook that opens outward for easy string attachment
    // Stem extends into arm body for solid union - NO floating spheres
    
    r_inner = hook_inner_diameter / 2;
    r_wire = hook_wire_thickness / 2;
    
    // Stem overlap into arm body for solid union
    stem_overlap = curved_arm_height + 2;
    
    mirror([0, flip ? 1 : 0, 0])
    union() {
        // Hook stem - extends UP into the arm body for proper union
        translate([0, 0, -hook_depth/3])
        cylinder(r = r_wire, h = hook_depth/3 + stem_overlap, $fn = 24);
        
        // C-curve of hook - simple, no ball tips
        translate([0, 0, -hook_depth])
        rotate([0, 90, -90 + hook_opening_angle/2])
        rotate_extrude(angle = 270 - hook_opening_angle, convexity = 4, $fn = 48)
        translate([r_inner + r_wire, 0, 0])
        circle(r = r_wire, $fn = 16);
    }
}

// ----------------------------------------------------------------------------
// AESTHETIC CHANNELS
// ----------------------------------------------------------------------------

// Simple channel - single groove down center
module center_channel() {
    steps = curve_segments / 2;
    
    for (i = [2:steps-3]) {
        t1 = i / steps;
        t2 = (i + 1) / steps;
        
        p1 = arm_curve_point(t1);
        p2 = arm_curve_point(t2);
        
        hull() {
            translate(p1 + [0, 0, arm_height_at(t1)/2 - channel_depth + 0.5])
            scale([1, channel_width/channel_depth, 1])
            sphere(d = channel_depth * 2, $fn = 12);
            
            translate(p2 + [0, 0, arm_height_at(t2)/2 - channel_depth + 0.5])
            scale([1, channel_width/channel_depth, 1])
            sphere(d = channel_depth * 2, $fn = 12);
        }
    }
}

// ----------------------------------------------------------------------------
// COMPLETE CURVED ARM (design orientation)
// ----------------------------------------------------------------------------

module arm_curved_design() {
    // Arm in design orientation (curve arching upward in Z)
    color(color_arms)
    difference() {
        union() {
            // Main curved body
            curved_arm_body();
            
            // Mounting tab at base
            mounting_tab();
            
            // Integrated hooks - properly merged with arm body
            for (h = [0:hook_count-1]) {
                // Distribute hooks evenly, avoiding the very ends
                t = 0.35 + h * 0.4 / max(1, hook_count - 1);
                
                p = arm_curve_point(t);
                
                // Position hook so stem extends into arm body
                translate(p + [0, 0, -arm_height_at(t)/2])
                hook_integrated(h % 2 == 1);  // Alternate hook direction
            }
        }
        
        // Subtract aesthetic channels
        center_channel();
    }
}

// ----------------------------------------------------------------------------
// COMPLETE CURVED ARM (print orientation)
// ----------------------------------------------------------------------------

module arm_curved() {
    // Rotate to print orientation: laying on side, curve pointing up
    // This avoids supports and gives better layer adhesion along arm length
    rotate([90, 0, 0])
    arm_curved_design();
}

// ----------------------------------------------------------------------------
// ALTERNATIVE STYLES
// ----------------------------------------------------------------------------

// Minimal - no channels
module arm_curved_minimal() {
    rotate([90, 0, 0])
    color(color_arms)
    union() {
        curved_arm_body();
        mounting_tab();
        
        for (h = [0:hook_count-1]) {
            t = 0.35 + h * 0.4 / max(1, hook_count - 1);
            p = arm_curve_point(t);
            
            translate(p + [0, 0, -arm_height_at(t)/2])
            hook_integrated(h % 2 == 1);
        }
    }
}

// ----------------------------------------------------------------------------
// ARM SET (ALL 4 FOR PRINT PLATE)
// ----------------------------------------------------------------------------
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

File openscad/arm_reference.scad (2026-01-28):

// ============================================================================
// Luna's Baby Mobile - Reference Arm Recreation
// ============================================================================
// Recreated from "Gentle Rotating Baby Mobile" reference STL
// Original design analyzed and rebuilt parametrically in OpenSCAD
// ============================================================================

$fn = 64;

// ----------------------------------------------------------------------------
// ARM PARAMETERS (extracted from reference STL)
// ----------------------------------------------------------------------------

arm_thickness = 12;  // Z height

// Centerline path extracted from reference (normalized to origin)
// Format: [x, y] - the arm curves through XY plane
centerline = [
    [0.0, 0.0],
    [5.7, 4.3],
    [11.4, 3.1],
    [17.1, 7.3],
    [22.8, 12.5],
    [28.5, 23.7],
    [34.2, 37.6],
    [39.9, 48.6],
    [45.6, 57.0],
    [51.3, 65.0],
    [57.0, 73.7],
    [62.7, 81.4],
    [68.5, 88.1],
    [74.8, 94.7],
    [80.8, 101.2],
    [86.8, 107.4],
    [92.5, 112.8],
    [98.3, 118.1],
    [104.6, 123.9],
    [110.3, 121.9],
    [116.0, 124.5],
    [121.7, 127.3],
    [127.6, 139.0],
    [134.0, 145.6],
    [142.6, 151.4],
    [149.3, 155.4],
    [155.0, 158.7],
    [161.5, 157.7],
    [172.3, 162.2],
    [178.0, 146.5],
    [189.0, 153.7]
];

// Width at each centerline point (for the arm cross-section)
// Wider sections = hook locations
widths = [
    12.6,   // narrow start (mounting end)
    32.0,
    58.1,
    69.0,   // first hook area starts
    77.6,   // hook 1
    74.0,
    64.9,
    60.9,
    58.3,
    56.3,
    56.2,
    54.5,
    54.2,
    54.0,
    53.9,
    53.8,
    52.3,
    53.6,
    53.8,
    66.4,   // second hook area starts
    72.4,
    75.0,   // hook 2
    59.8,
    57.0,
    58.0,
    57.5,
    57.9,
    49.6,
    50.2,
    13.6,   // narrow tip
    19.8
];

// Hook positions (indices into centerline where hooks are)
hook_indices = [4, 21];  // At the widest points

// ----------------------------------------------------------------------------
// HELPER FUNCTIONS
// ----------------------------------------------------------------------------

// Linear interpolation
function lerp(a, b, t) = a + (b - a) * t;

// Get width at a specific index (clamped)
function get_width(i) = widths[min(max(0, i), len(widths)-1)];

// ----------------------------------------------------------------------------
// ARM BODY - Built by hulling cross-sections along the path
// ----------------------------------------------------------------------------

module arm_cross_section(width) {
    // Rounded rectangular cross-section (pill shape)
    hull() {
        translate([0, -width/2 + arm_thickness/2, 0])
            cylinder(h = arm_thickness, d = arm_thickness, center = true);
        translate([0, width/2 - arm_thickness/2, 0])
            cylinder(h = arm_thickness, d = arm_thickness, center = true);
    }
}

module arm_body() {
    for (i = [0:len(centerline)-2]) {
        p1 = centerline[i];
        p2 = centerline[i+1];
        w1 = get_width(i);
        w2 = get_width(i+1);
        
        hull() {
            translate([p1[0], p1[1], 0])
                arm_cross_section(w1);
            translate([p2[0], p2[1], 0])
                arm_cross_section(w2);
        }
    }
}

// ----------------------------------------------------------------------------
// INTEGRATED HOOKS
// ----------------------------------------------------------------------------

module hook(flip = false) {
    // C-shaped hook pointing downward (in -Z when arm is flat)
    hook_wire = 3;
    hook_inner_r = 4;
    hook_depth = 15;
    
    mirror([0, flip ? 1 : 0, 0])
    translate([0, 0, 0]) {
        // Stem connecting to arm
        cylinder(r = hook_wire/2, h = arm_thickness/2 + 2, $fn = 24);
        
        // C-curve
        translate([0, 0, -hook_depth + hook_inner_r])
        rotate([0, 90, -60])
        rotate_extrude(angle = 240, $fn = 48)
        translate([hook_inner_r, 0, 0])
            circle(d = hook_wire, $fn = 16);
    }
}

module hooks_at_position(idx) {
    p = centerline[idx];
    w = get_width(idx);
    
    translate([p[0], p[1], -arm_thickness/2]) {
        // Two hooks, one on each side of the arm
        translate([0, -w/4, 0]) hook(false);
        translate([0, w/4, 0]) hook(true);
    }
}

// ----------------------------------------------------------------------------
// DECORATIVE CHANNEL (recessed groove along top)
// ----------------------------------------------------------------------------
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

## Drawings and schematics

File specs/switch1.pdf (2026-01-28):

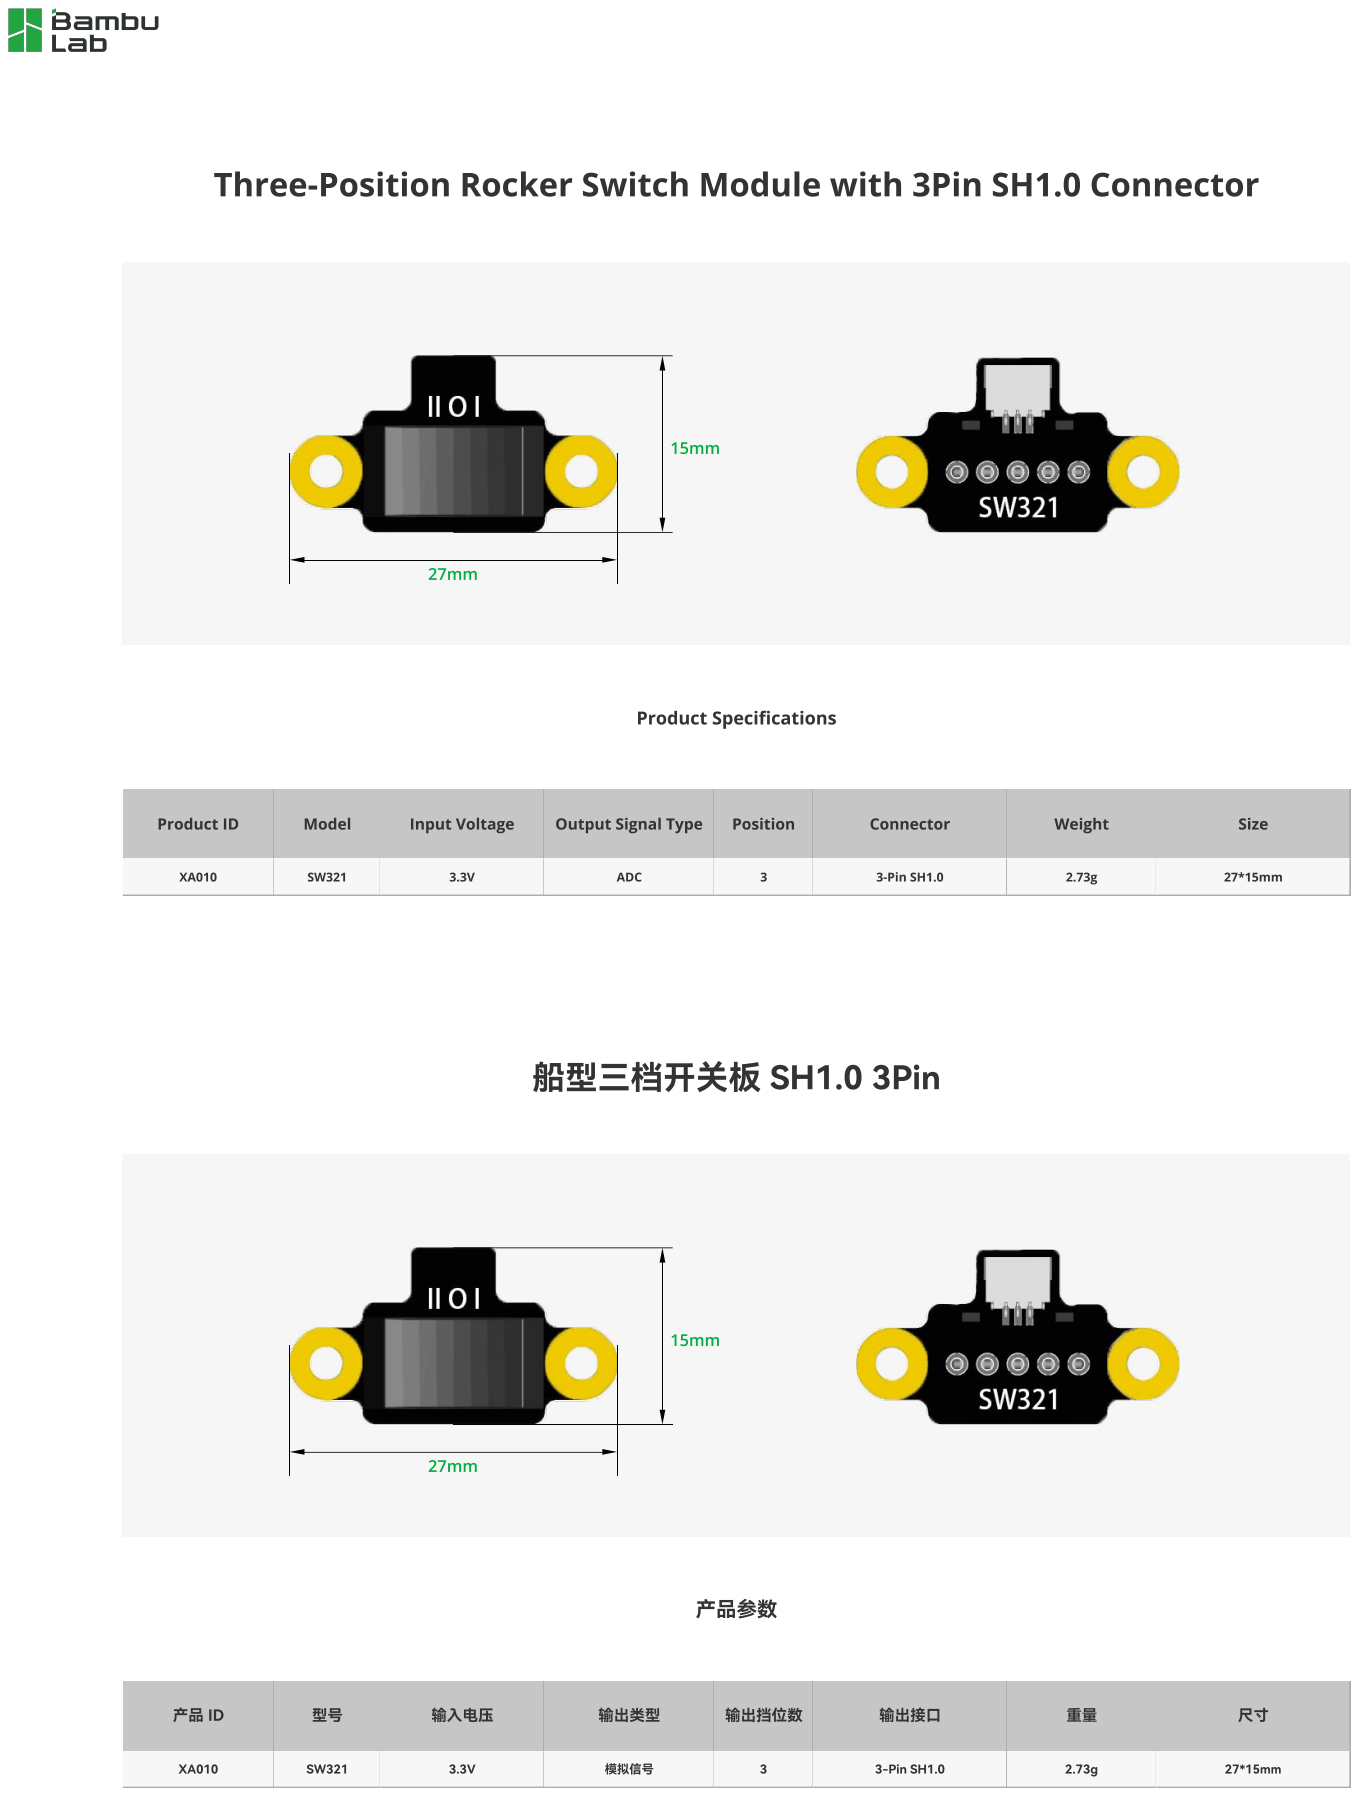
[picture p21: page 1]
Product Specifications; Product ID; Model; Input Voltage; ADC; Position; Connector; 3-Pin SH1.0; Weight; Size; 船型三档开关板 SH1.0 3Pin; 产品参数; 输入电压; 输出类型; 模拟信号; 输出挡位数; 输出接口

Three-Position Rocker Switch Module with 3Pin SH1.0 Connector

Output Signal Type

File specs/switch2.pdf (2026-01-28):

# Power Switch Module with 2Pin XH2.54 Connector

2025/04/21

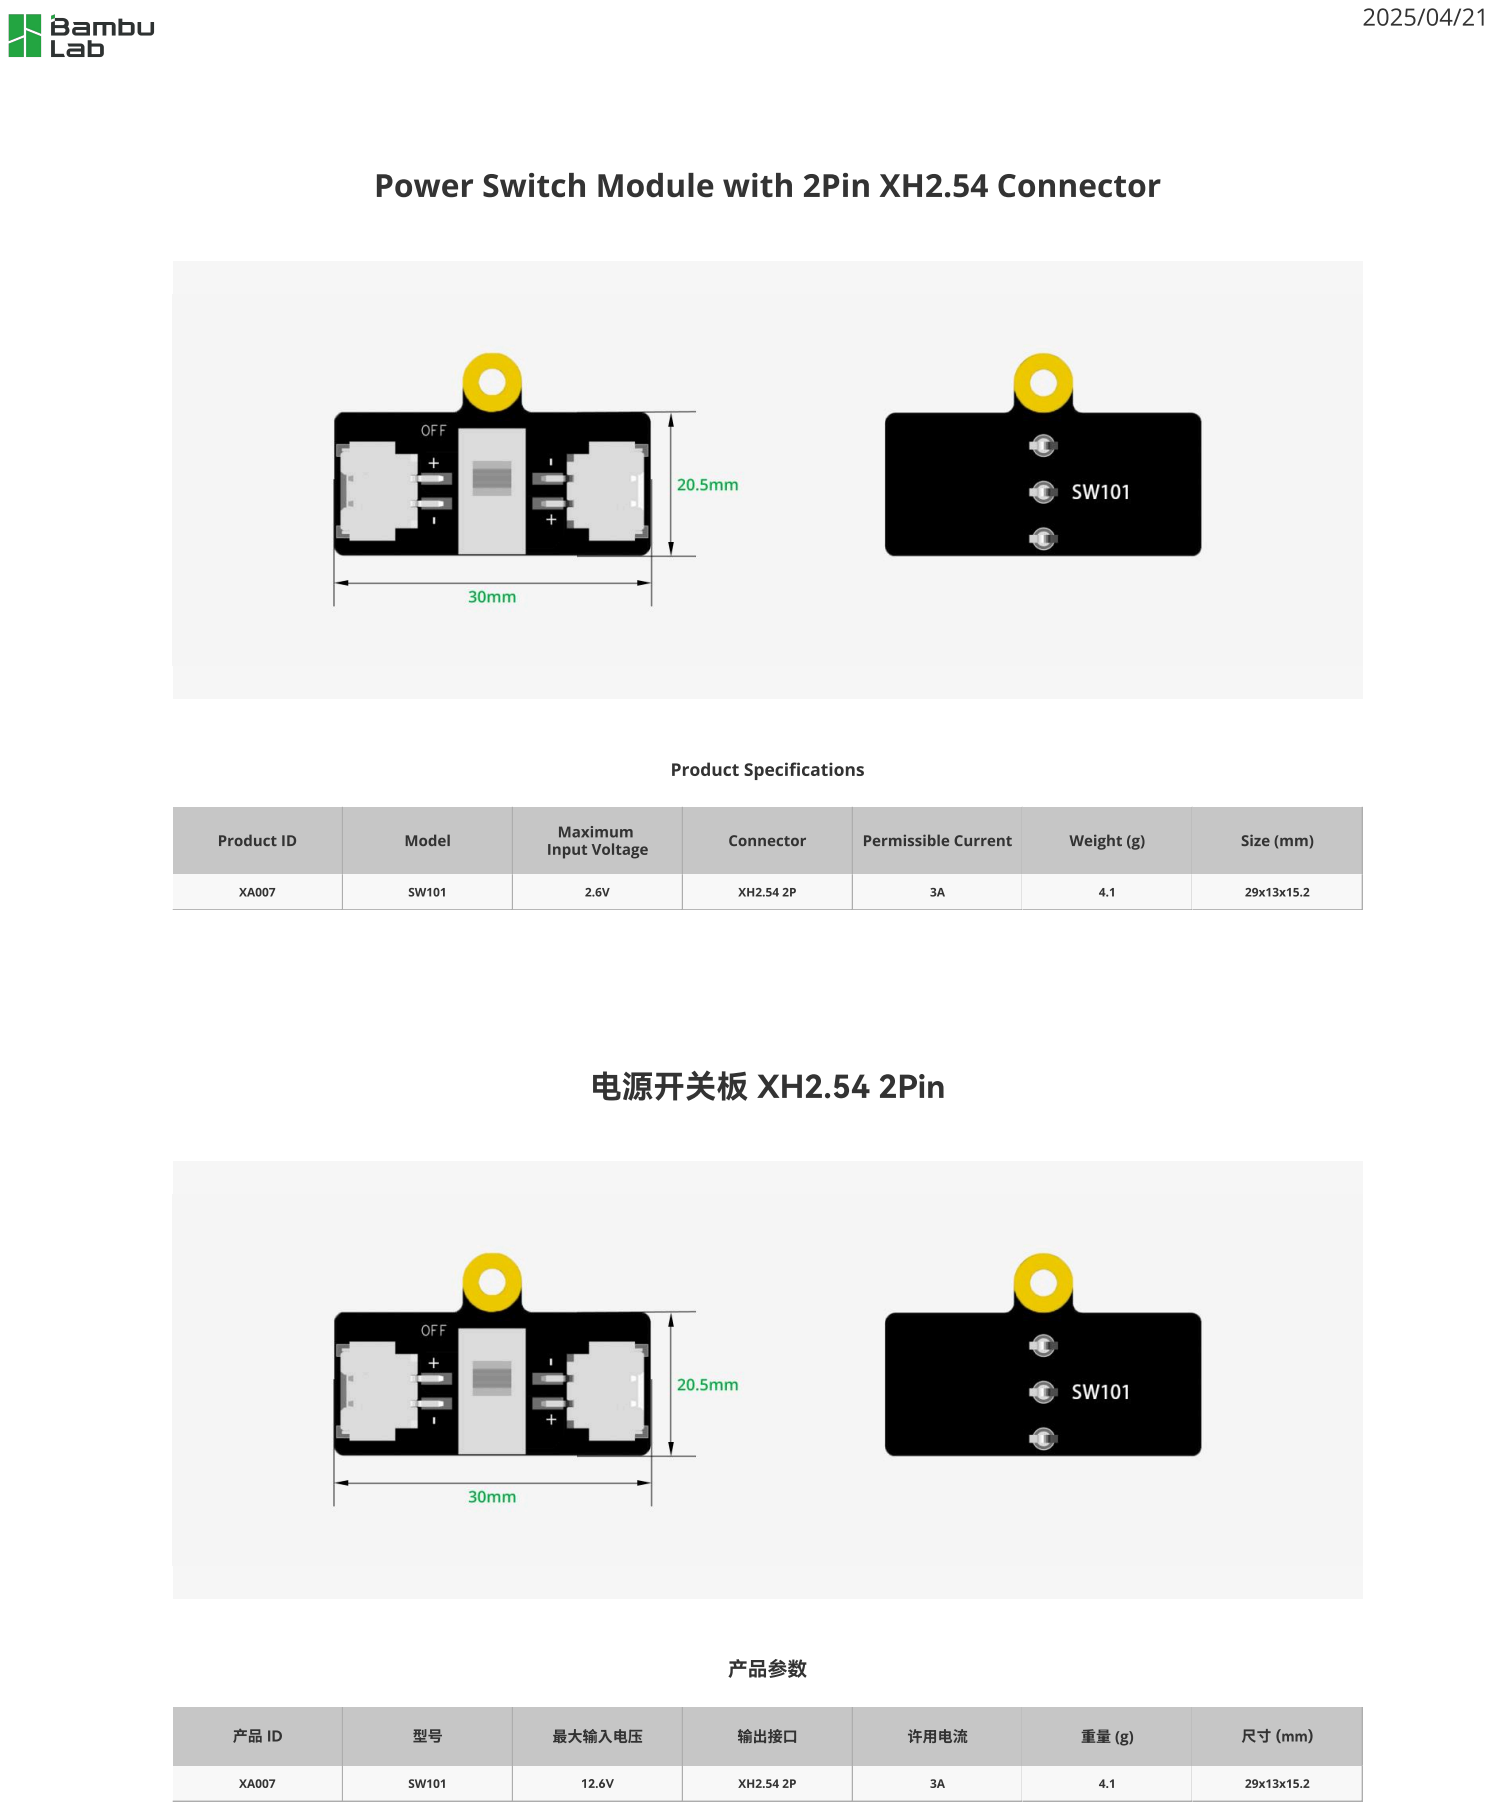
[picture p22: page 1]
Product Specifications; Product ID; Model; Maximum; Input Voltage; Connector; Permissible Current; Weight (g); Size (mm); 电源开关板 XH2.54 2Pin; 产品参数; 最大输入电压; 输出接口; 许用电流

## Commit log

2026-01-28 🌙 Initial commit: Luna's Baby Mobile
    A beautiful, motorized baby mobile designed for 3D printing.
    Features:
    - Parametric OpenSCAD design
    - Two-stage 50:1 gear reduction (150 RPM → 3 RPM)
    - 608 bearing for smooth rotation
    - Ceiling mount and crib rail clamp options
    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
    [608 Open - EA029.stl, 608 Open - EA029.stp, 608ZZ P5 - EA028.stl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]
2026-01-28 Major update: Simplified design with new components
    🔧 Motor Update:
    - Switched from dual-shaft (B-LA009) to single-shaft (B-LA008)
    - 6V rated, ~30 RPM (instead of 3V, 150 RPM)
    - Updated motor_mount.scad for single shaft with ventilation
    ⚙️ Gear Simplification:
    - Reduced from 50:1 two-stage to 8:1 single-stage
    - 12T pinion → 96T output gear
    - 30 RPM ÷ 8 = ~3.75 RPM (perfect gentle rotation)
    - Much simpler, fewer failure points!
    🔋 Power System (New):
    - Added battery_mount.scad for 4xAA case (IA003)
    - Added switch_mount.scad for XA007 power switch
    - Added barrel_jack.scad for optional DC wall power
    - Dual power options: battery or wall adapter
    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
    [3x1.5V AAA Battery Case with XH2.54 Connector-XA012.stl, 3x1.5V AAA Battery Case with XH2.54 Connector-XA012.stp, AAA_battery_case_with_wire_ph2_0.stl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]
2026-01-28 Add Power Distribution Board (IA005) mount and documentation
    - Created openscad/pdb_mount.scad: Parametric mount for 53×10×10mm board
    - M2 screw holes for secure board mounting
    - Assembly mounting tabs with M3 holes
    - Cable routing channels for all connector sides
    - LED viewing window for status indicator
    - Board retention clips for secure fit
    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
    [assembly.scad, pdb_mount.scad, power_distribution_board_new.stl]
2026-01-28 🎨 Add rendered STL files for all printable parts
    [arm.stl, barrel_jack.stl, battery_mount.stl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]
2026-01-28 Add curved arm design with integrated hooks
    ✨ New curved arm style (arm_curved.scad):
    - Elegant sweeping arc shape inspired by Scandinavian design
    - Two integrated downward-facing hooks for hanging decorations
    - Decorative recessed channel along the top surface
    - M3 mounting holes for secure hub attachment
    - Fully parametric (length, width, curve, hooks, channels)
    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
    [arm.scad, arm_curved.scad, arm_straight.scad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]
2026-01-28 Fix curved arm printability issues
    - Fixed floating hooks: Extended hook stems into arm body for proper union
    - Added print orientation: Rotated 90° to lay flat (curve pointing up)
    - Removed mounting screw holes: Tab is now solid (connection method TBD)
    - Verified manifold: OpenSCAD reports 'Simple: yes' (valid mesh)
    [arm_curved.scad]
2026-01-28 🔧 Fix curved arm: single arm, remove floating spheres, properly attached hooks
    [arm_curved.scad]
2026-01-28 ✨ Add reference arm recreation from analyzed STL
    [arm_reference.scad, arm_reference.stl]
